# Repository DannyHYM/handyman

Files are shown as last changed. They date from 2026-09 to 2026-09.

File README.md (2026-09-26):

# Handyman

Handyman is a small mechanical cube for fine motor practice. You hold it in one hand and turn a knob with the other. The turn is the same kind of motion used on a stove dial, a handle, or a small control, and the resistance can be raised as the hand gets stronger.

It was designed for hand recovery after a burn, where rotation and grip have to be rebuilt in graded steps.

There is no motor, sensor, battery, or software. Resistance comes from friction inside the cube.

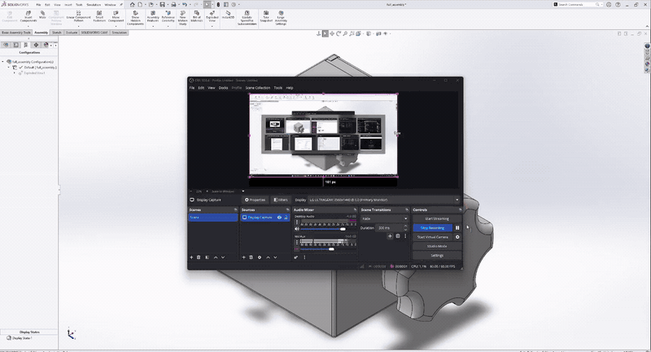
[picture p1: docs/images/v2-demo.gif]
Version 2 of Handyman in SolidWorks: the assembled cube, the lid opening onto the shaft and split clamp, then the parts pulled apart


Version 2, played from the design model.

## What the cube trains

Most hand exercises ask you to squeeze. A ball, a piece of putty, or a grip trainer builds closing force. A lot of daily tasks are different. They ask the fingers to pinch a small shape and rotate it while the wrist stays relatively still: turning a stove knob, a faucet, a bottle cap, a door lock, or a dial on an appliance.

Those tasks are hard to grade. A household object is either turnable that day or it is not. Putty has no knob. A generic exerciser does not feel like the object the person is trying to get back to.

Handyman isolates that rotation. The cube is the stable body. The knob is the object. Difficulty is a property of the device, so the same motion can start easy and become harder without switching to a different tool.

The cube is meant for either hand. It is small enough for a clinic table or a desk.

## Primary Usecase

**Burn recovery.** After a hand burn, fine motor skill often has to be practiced on purpose: light pinch, controlled rotation, then a firmer turn, over many short sessions. Handyman gives that practice a single object. Version 1 grades the turn by which hole the knob sits in. Version 2 grades it with a screw, so the therapist or the user can change the load without taking the cube apart. The knob shapes are ordinary on purpose. Time spent turning them is time spent on the shapes of real controls.

## Where the project came from

This project was catalyzed by a collaboration between the USC Creative Media & Behavioral Health Center and the Burn Unit at Los Angeles General Medical Center (LAGMC), through a National Institute on Disability, Independent Living, and Rehabilitation Research (NIDILRR) grant. The grant’s principal investigator is Dr. Haig Yenikomshian, Associate Professor at the Keck School of Medicine and co-director of the LAGMC Burn Unit. Occupational therapists Karin Blen, Vivian Duprey Avalos, Joanna Madrid, and Joann Chun, of the LAGMC outpatient occupational therapy unit, were consulted on burn-recovery protocols for hand fine motor skill and gave verbal feedback on the prototype as it developed.

## How you use it

1. Hold the cube in the non-working hand, or brace it on a table.
2. Pinch the knob the way you would pinch the real object it stands in for.
3. Turn it through a comfortable arc, then back. The curved arrows on Version 1 mark that direction.
4. Raise the difficulty when the current setting is easy to finish: move the knob to a tighter hole (Version 1), or tighten the adjustment screw (Version 2).
5. Stop when the motion stops being controlled. For rehabilitation, that limit belongs to the therapist’s plan.

Short sets matter more than long ones. The device is there so the load can be repeated tomorrow at the same setting, or one step higher.

## Version 1

Version 1 is a rounded cube, 95 mm on each side, with four holes of different diameters. Each hole is a resistance level. A knob pressed into a larger hole turns more freely. The same knob pressed into a smaller hole meets more friction, so the turn is harder. Swapping knobs between holes is the whole adjustment.

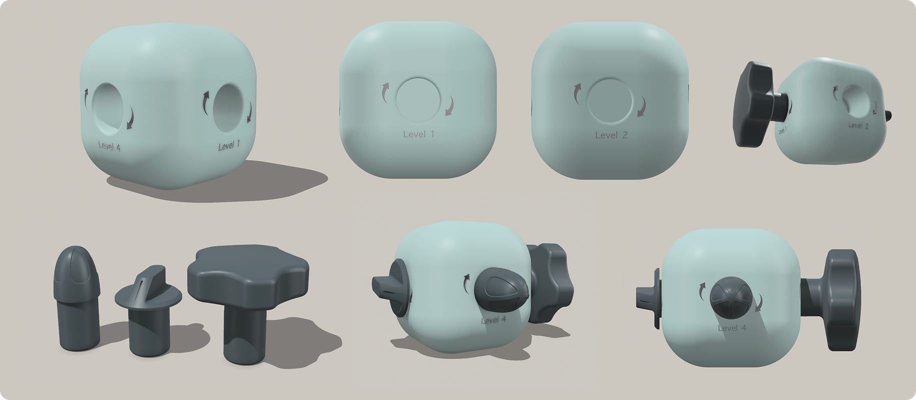
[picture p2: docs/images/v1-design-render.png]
Version 1 render: a rounded cube with level markings, three dark knobs, and the knobs installed on different faces


The faces carry a level number and a rotation arrow. The current knob set has three shapes, chosen because they resemble controls people already know:

| Knob | File | Envelope | Role |
| --- | --- | --- | --- |
| Narrower knob | [`v1/stl/handyman_knob1.stl`](v1/stl/handyman_knob1.stl) | 42 × 42 × 51 mm | The smaller, taller grip |
| Stove-style pointer | [`v1/stl/handyman_knob2.stl`](v1/stl/handyman_knob2.stl) | 66 × 29 × 29 mm | A long, narrow turn, like a stove dial |
| Large knob | [`v1/stl/handyman_knob3.stl`](v1/stl/handyman_knob3.stl) | 70 × 72 × 67 mm | A broad, lobed grip |

Three knobs and four holes give up to twelve pairings: a familiar shape combined with a tighter or looser fit, in one object that can be reprinted. Each level is a printed step in fit.

More than one knob can be installed at once. The photo below shows the cube in two hands with two knobs fitted, which is how a session actually looks: one hand stabilizes, the other turns.

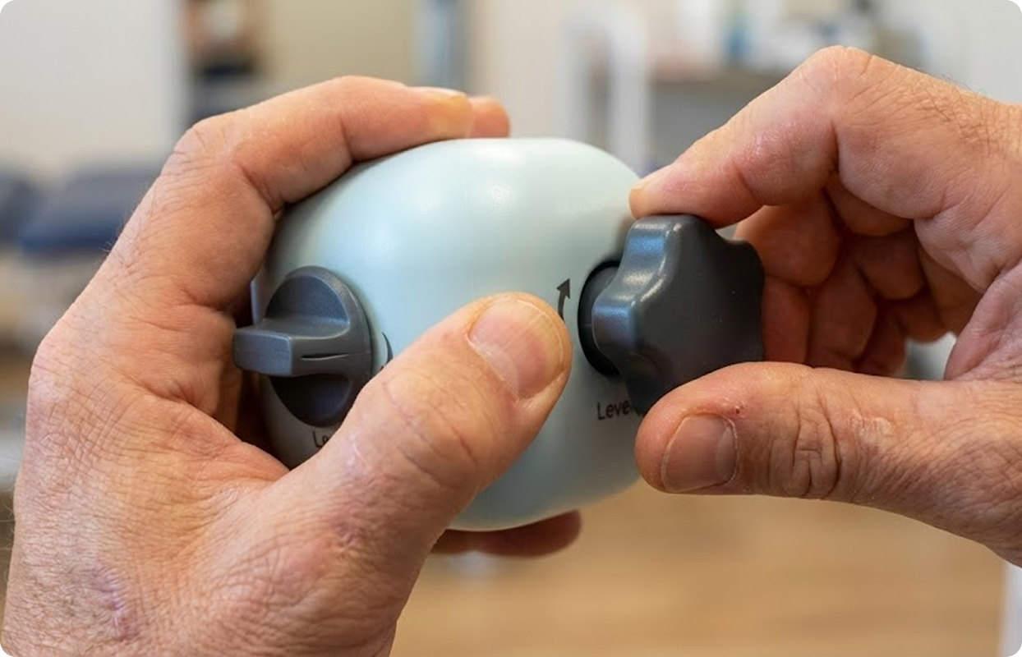
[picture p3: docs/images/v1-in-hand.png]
Version 1 held in both hands, with two knobs installed and a level marking visible on the face


[`v1/stl/Handyman_v1_cube.stl`](v1/stl/Handyman_v1_cube.stl) is the 95 mm body. [`v1/stl/handy_man_full.stl`](v1/stl/handy_man_full.stl) is the body and knobs laid out together, about 208 × 196 × 95 mm, for a single print plate.

Version 1 is simple, and that simplicity has a limit. A hole is one size once it is printed. A fit that comes out slightly tight or slightly loose is corrected with a different hole, a different knob, or a new print. Version 2 adds a screw so the same cube can be eased or firmed in small steps while you hold it.

## Version 2

Version 2 keeps the cube and the everyday knob, and moves the resistance into an adjustable clamp.

The body is a 105 mm case with a lid. A shaft runs through it. The knob mounts on the outer end of the shaft. Inside, the shaft passes through a split-clamp bushing: a sleeve with a slit down one side, in the same family as a collet. A screw on the opposite face pushes that sleeve closed.

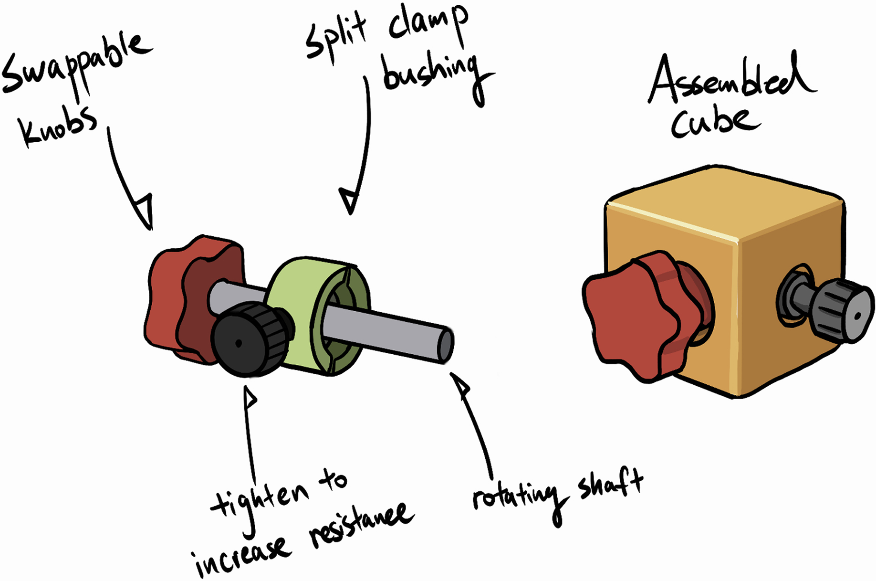
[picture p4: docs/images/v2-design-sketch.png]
Concept sketch of Version 2: a swappable knob on a shaft, a split-clamp bushing, a screw labeled as the resistance adjustment, and the assembled cube


With the screw backed off, the sleeve is relaxed and the shaft turns with little drag. Turning the screw in closes the slit, the sleeve grips the shaft more evenly, and the knob takes more torque to rotate. Backing the screw off lets the sleeve open again. The knob does not change. The setting does.

The torque at the fingers is friction torque. It depends on how hard the sleeve presses on the shaft, how much surface is in contact, and the radius of the shaft. The screw only sets that pressure. One device then covers a continuous range from an easy turn to a firm one.

| Assembled | Open, so the shaft and clamp are visible |
| --- | --- |
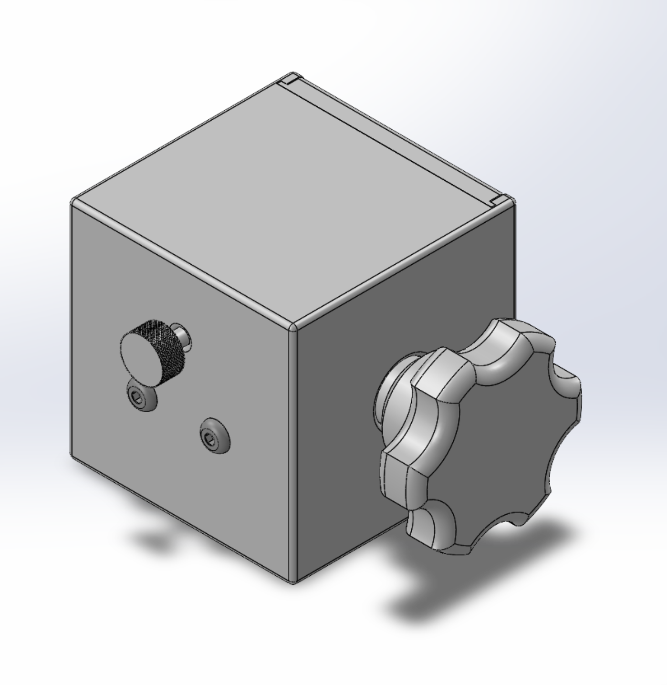
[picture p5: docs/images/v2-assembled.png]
Version 2 assembled: star knob on the front face, knurled adjustment screw and two fasteners on the side
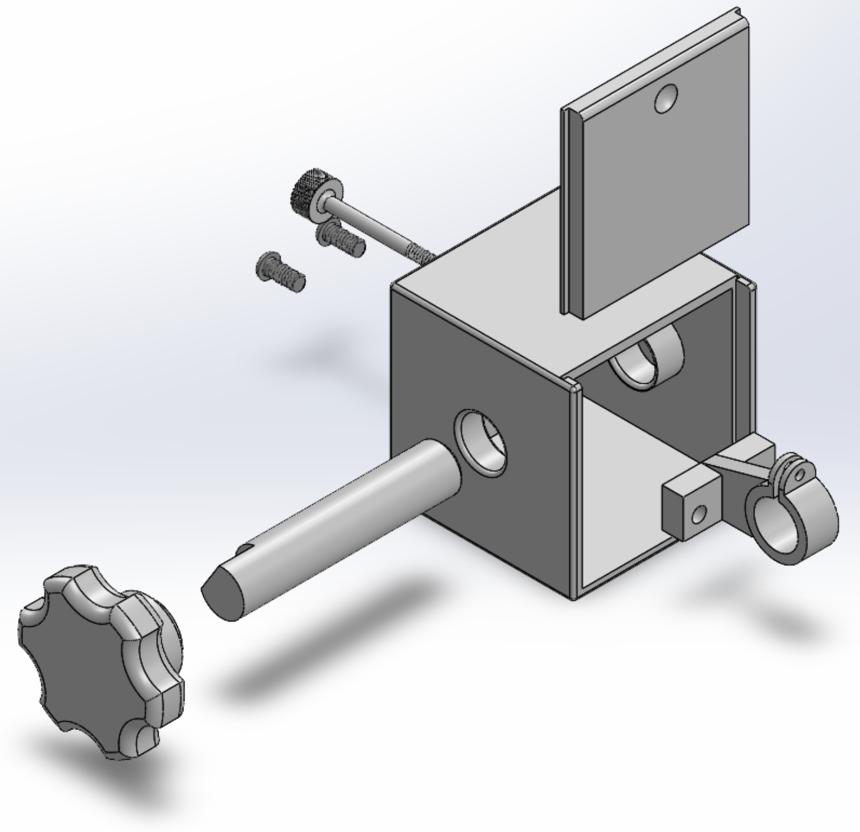
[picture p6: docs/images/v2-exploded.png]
Version 2 exploded: knob, shaft, case, lid, split clamp, adjustment screw, and lid screws
|  |  |

The parts, measured from the print files:

| Part | File | Size |
| --- | --- | --- |
| Case | [`v2/print/case.STL`](v2/print/case.STL) | 105 × 105 × 105 mm |
| Lid | [`v2/print/lid.STL`](v2/print/lid.STL) | 100 × 99.8 mm, 10 mm thick |
| Rotating shaft | [`v2/print/rotating_shaft.STL`](v2/print/rotating_shaft.STL) | 25 mm diameter, 125 mm long, with a short 21 mm end |
| Knob | [`v2/print/knob.STL`](v2/print/knob.STL) | about 80 mm across and 40 mm thick |
| Split clamp, closer bore | [`v2/print/split_clamp_6.43mm.STL`](v2/print/split_clamp_6.43mm.STL) | 65 × 45.4 × 52 mm, 6.43 mm bore |
| Split clamp, looser bore | [`v2/print/split_clamp_6.48mm.STL`](v2/print/split_clamp_6.48mm.STL) | same envelope, 6.48 mm bore |
| Adjustment screw | [`v2/print/tighten_screw.STL`](v2/print/tighten_screw.STL) | 6.4 mm shank, 75 mm long, 20 mm knurled head |
| Lid screws | [`v2/print/screws.STL`](v2/print/screws.STL) | the pair that closes the lid |

The knob is its own part, so the grip can be swapped without redesigning the clamp. The print set includes the star knob shown in the renders. The sketch calls that out as a swappable knob: the shape can follow the task, while the resistance still comes from the screw.

The two clamp files are the same part exported at two bores, 0.05 mm apart. Printed holes rarely come out at the modeled size. The pair lets you pick the clearance that actually turns freely when the screw is loose and firms up when the screw is tightened. Start with 6.48 mm if the shaft binds with the screw fully backed off. Use 6.43 mm if the looser clamp never develops a clear resistance.

Editable SolidWorks files are in [`v2/solidworks`](v2/solidworks). The assembly is [`full_assembly.SLDASM`](v2/solidworks/final_assembly/full_assembly.SLDASM). Part files and drawings sit beside it. Check the mates there before a final print. The STLs are the print exports of that model.

## What changed between versions

| | Version 1 | Version 2 |
| --- | --- | --- |
| Body | Rounded 95 mm cube | 105 mm case with a removable lid |
| What you turn | Three knobs: pointer, large, and narrow | A shaft-mounted knob, with the star knob in the print set |
| How resistance is set | Hole diameter. Move the knob to another face | A screw closes a split clamp around the shaft |
| Steps | Four printed levels, combined with three knobs | Continuous, between loose and firm |
| In use | Several knobs can be installed together | One axis, adjusted from the opposite face |
| Correction after printing | Reprint, or use a different hole | Turn the screw, or switch clamp bore |

Version 1 is the better demonstration of “this knob feels like that object.” Version 2 is the better training device, because the load can be changed in the hand, in small amounts, and then left there for the next session.

## Printing

The files are millimeters. Version 1 is STL only. Version 2 can be printed from [`v2/print`](v2/print) or changed in SolidWorks and exported again.

A rigid filament is the right material. The clamp has to spring back when the screw is loosened, and the shaft has to stay round, so a soft or very flexible filament works against the mechanism.

A few fits dominate the print:

- Print the shaft so its axis stays round. A shaft printed lying down can come out slightly oval, and an oval shaft makes the drag uneven through the turn.
- Keep the slit in the clamp open. If the slit fuses, the screw has nothing to close.
- Print one clamp first, test it on the shaft with the screw removed, then print the other bore only if you need it.
- The lid is a 10 mm plate. It closes the case and is held by the two small screws.
- The adjustment screw has a knurled head so it can be turned by hand, without a driver, between sets.

No specific layer height or infill is required by the design. The bores are the sensitive dimensions. If your printer runs large or small, the 0.05 mm clamp pair is the intended compensation.

### Assembly, Version 2

1. Set the split clamp inside the case so its bore lines up with the shaft holes.
2. Slide the shaft through the case and through the clamp.
3. Mount the knob on the outer end of the shaft.
4. Thread the adjustment screw in from the opposite face until it bears on the clamp. Leave it loose.
5. Fit the lid and fasten it with the two small screws.
6. Turn the knob. It should spin. Tighten the knurled screw a little at a time until the turn has the resistance you want. Mark that position if you need the same load next time.

To go back to an easy turn, loosen the screw. Difficulty stays adjustable with the lid on.

## Timeline

| Date | What happened |
| --- | --- |
| September 23, 2025 | Concept |
| September 24 – November 17, 2025 | Sketches and the Version 1 design |
| September 26, 2025 | First conversation with the outpatient occupational therapists |
| November 18, 2025 | First printed Version 1 |
| December 9, 2025 | Second conversation, on the printed cube |
| December 10, 2025 onward | Version 2: the split clamp and the adjustment screw |
| March 9, 2026 | Version 2 model walkthrough recorded |

## Repository

```
docs/
  images/          renders, the Version 2 sketch, and the demo GIF
  media/           full Version 2 demo video
v1/
  stl/             Version 1 cube, three knobs, and the combined plate
v2/
  print/           print-ready STLs
  solidworks/
    required_parts/    editable parts
    final_assembly/    assembly
    drawings/          drawings
```

SolidWorks references are relative between `final_assembly`, `required_parts`, and `drawings`. Keep those three folders side by side if you move the CAD.

## Contributors

- Yiming “Danny” Huang
- Violet Wong
- Caitlyn Guo
- Ash Kim
- Yiqi “Kiwi” Li
- Marientina Gotsis

Clinical consultation, through the LAGMC outpatient occupational therapy unit: Karin Blen, Vivian Duprey Avalos, Joanna Madrid, and Joann Chun, with Dr. Haig Yenikomshian as principal investigator of the NIDILRR grant that brought the collaboration together.

## License

The design files, images, video, and this documentation are released under [CC BY-NC 4.0](https://creativecommons.org/licenses/by-nc/4.0/). You can copy, share, and build Handyman for non-commercial use if you credit the contributors. Commercial use is not allowed. The full notice is in [`LICENSE`](LICENSE).

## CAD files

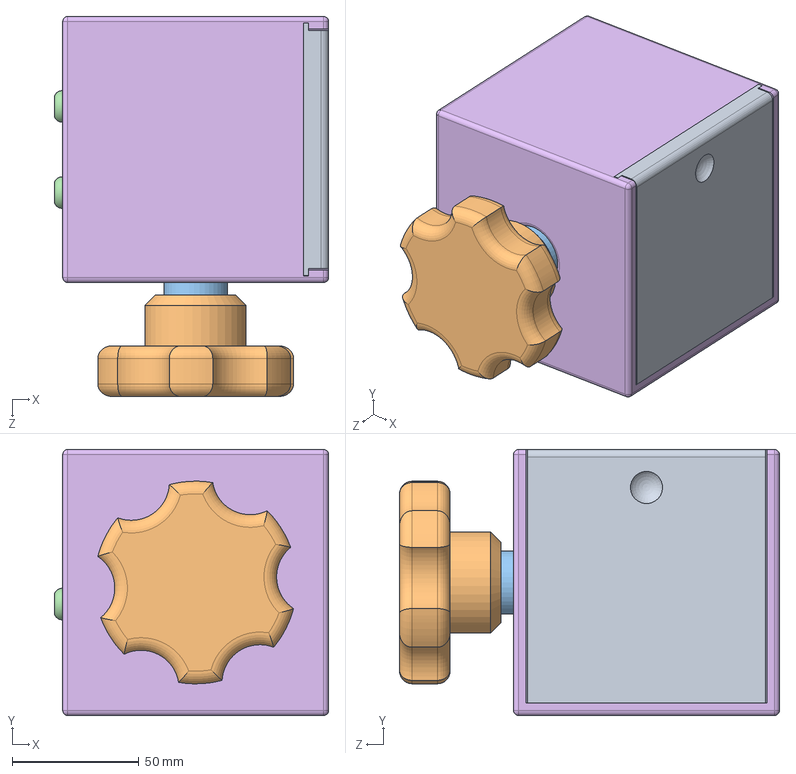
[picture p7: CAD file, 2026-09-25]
v2/solidworks/final_assembly/full_assembly.SLDASM
108.3 x 105.0 x 150.0 mm
case
split_clamp
screws x 2
rotating_shaft
knob
lid

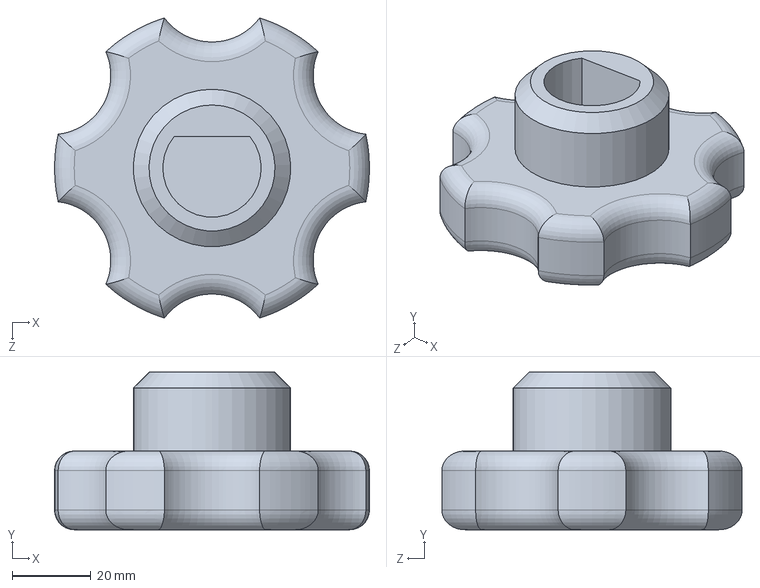
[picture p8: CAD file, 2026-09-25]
v2/solidworks/required_parts/knob.SLDPRT
80.0 x 40.0 x 76.3 mm

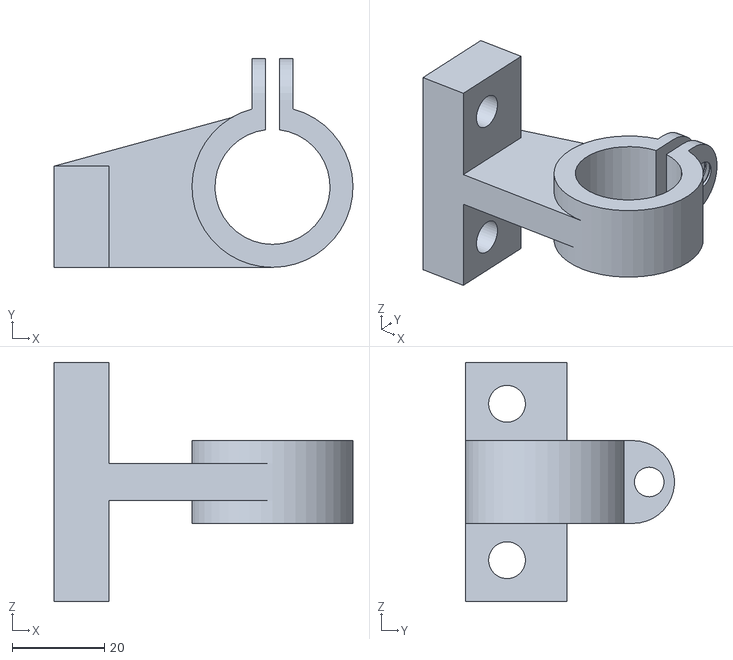
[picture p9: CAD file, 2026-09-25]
v2/print/split_clamp_6.43mm.STL
65.0 x 45.4 x 52.0

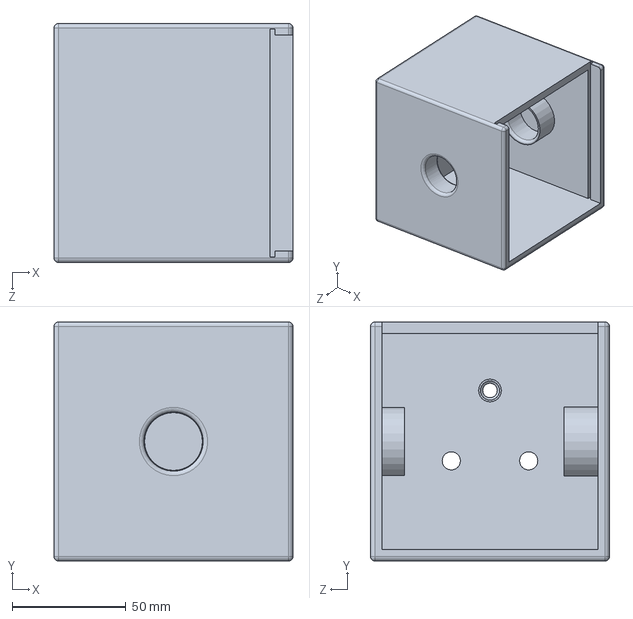
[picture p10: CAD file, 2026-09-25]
v2/solidworks/required_parts/case.SLDPRT
105.0 x 105.0 x 105.0 mm

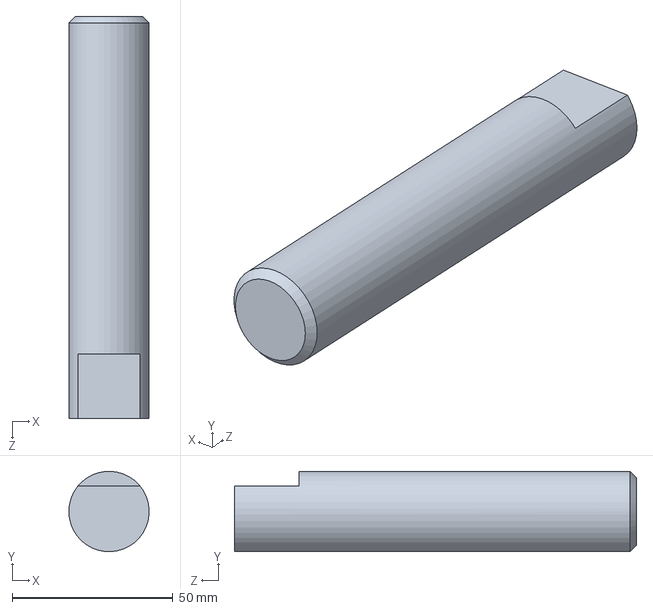
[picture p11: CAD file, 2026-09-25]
v2/solidworks/required_parts/rotating_shaft.SLDPRT
25.0 x 25.0 x 125.0 mm

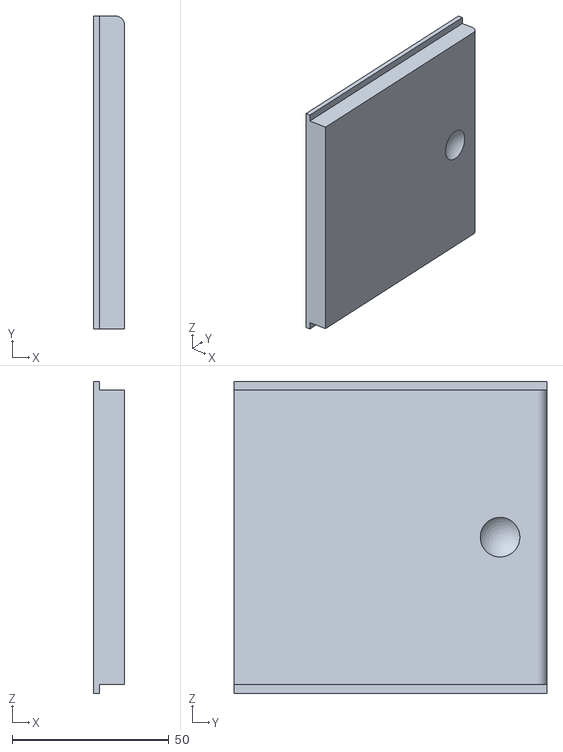
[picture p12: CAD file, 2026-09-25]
v2/print/lid.STL
10.0 x 100.0 x 99.8

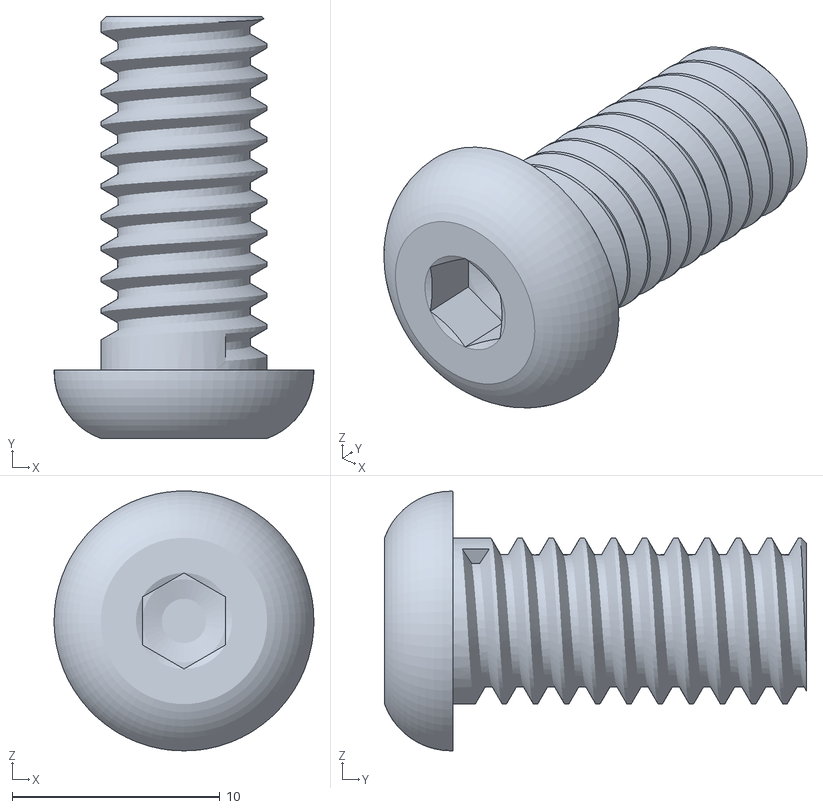
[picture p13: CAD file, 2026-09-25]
v2/print/screws.STL
12.5 x 20.3 x 12.5

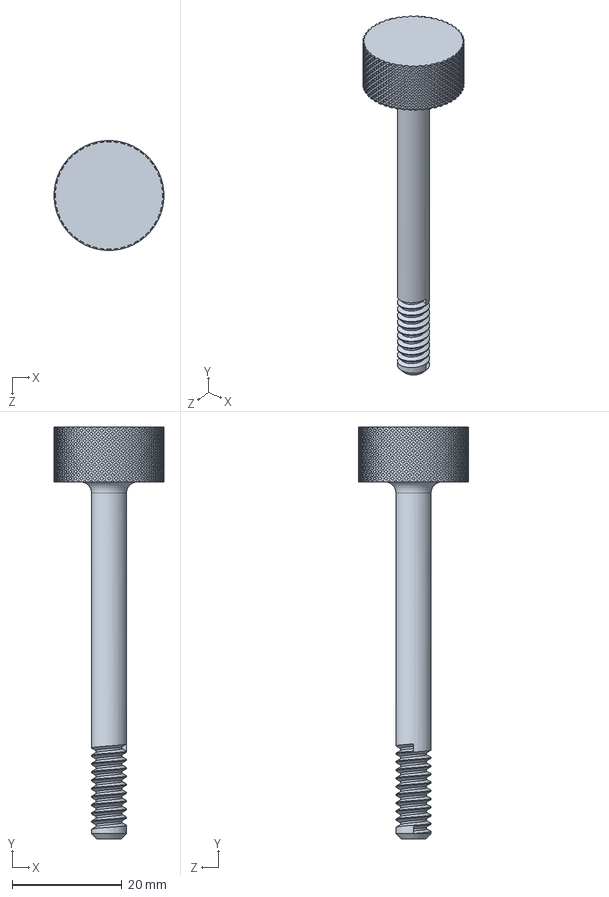
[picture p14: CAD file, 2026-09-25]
v2/solidworks/required_parts/tighten_screw.SLDPRT
20.0 x 75.0 x 20.0 mm

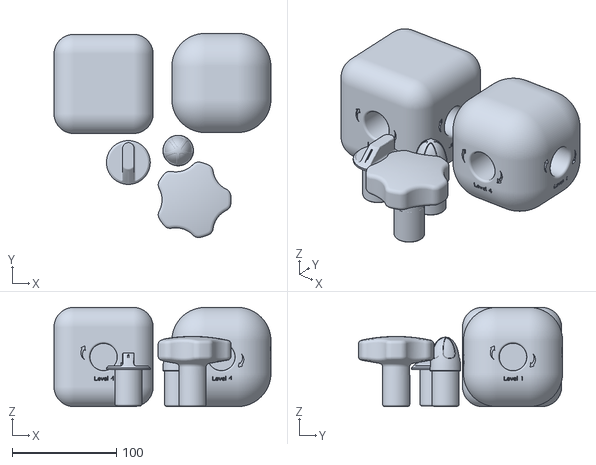
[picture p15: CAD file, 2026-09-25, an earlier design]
v1/stl/handy_man_full.stl
207.9 x 195.6 x 95.0

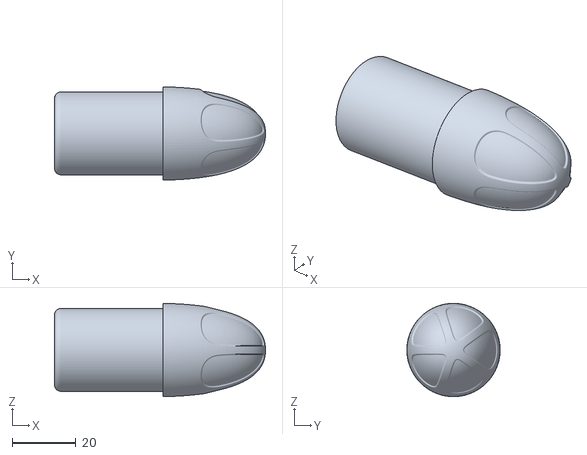
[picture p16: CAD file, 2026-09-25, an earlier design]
v1/stl/handyman_knob2.stl
66.3 x 29.3 x 29.3

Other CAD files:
v2/print/case.STL
v2/print/rotating_shaft.STL
v2/solidworks/required_parts/split_clamp.SLDPRT
v2/print/knob.STL
v2/solidworks/required_parts/lid.SLDPRT
v2/print/split_clamp_6.48mm.STL
v2/print/tighten_screw.STL
v2/solidworks/required_parts/screws.SLDPRT
v1/stl/Handyman_v1_cube.stl
v1/stl/handyman_knob1.stl
v1/stl/handyman_knob3.stl
v2/solidworks/drawings/case.SLDDRW
v2/solidworks/drawings/full_assembly.SLDDRW
v2/solidworks/drawings/knob.SLDDRW
v2/solidworks/drawings/lid.SLDDRW
v2/solidworks/drawings/rotating_shaft.SLDDRW
v2/solidworks/drawings/screws.SLDDRW
v2/solidworks/drawings/split_clamp.SLDDRW
v2/solidworks/drawings/tighten_screw.SLDDRW

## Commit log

2026-09-25 Added 3D print files for V1 and V2 of the cube
    [Handyman_v1_cube.stl, case.STL, handy_man_full.stl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]
2026-09-25 added the solidworks design files for V2
    [case.SLDDRW, case.SLDPRT, case.STL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]
2026-09-26 Document Handyman for the public repo and organize the V1 and V2 design files.
    [Handyman_v1_cube.stl, case.SLDDRW, case.SLDPRT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]
